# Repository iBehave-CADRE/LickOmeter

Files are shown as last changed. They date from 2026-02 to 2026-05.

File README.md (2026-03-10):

# LickOmeter

This is a guide to build your own motorized LickOmeter based on the arduino capacitive sensor library. Measuring the capacity allows detection of individual licks and therefore direct reward acceptance in the context of many different behavioral research experiments. The final product, can run individually as an embedded system and allows integration with other devices for behavioral research. The repository provides all necessary information to reproduce this device and coding exercises for the general understanding of the resulting data.

Only basic Arduino skills like connecting and uploading code are required for this tutorial.

---

## System Integration

The device modular integration in existing experimental instruments using 5V Digital/Analog TTL signaling via coaxial BNC cables (e.g. with NI-DAQ, cDAQ or dSpace Microlabox) or using Serial Communication via a USB cable (e.g. Python, MATLAB, Bonsai). For the future, integration in the bPod system is planned.

The current firmware allows to control the position of the lickspout with a 5V Digital via a coaxial BNC cable (0V):

0V (LOW) -> Lickspout OUT  
5V (HIGH) -> Lickspout IN

Coupling the Lick-OUT signal with a syringe pump, peristaltic pump or solenoid valve allows controlled application of reward. Also, the LickOmetor can run independently if powered with a 12V power supply and does not necessarily need to be connected to a computer.

Modification of this firmware would also allow to control the lickspout with Serial Communication via USB.

---

## Lickspout Motorization

Currently, two actuators are implemented for custom use cases. The rotary actuator directly couples servo motor rotation to the lickspout, while the linear actuator transforms servo motor rotation via a gear-rack system to linear motion.

### Rotary Actuator

<p align="center">
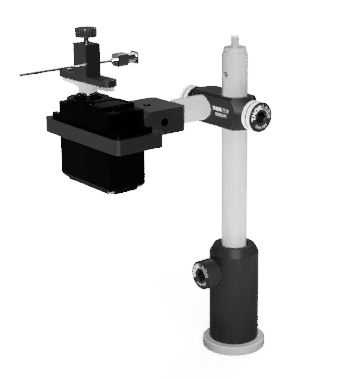
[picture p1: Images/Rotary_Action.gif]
  
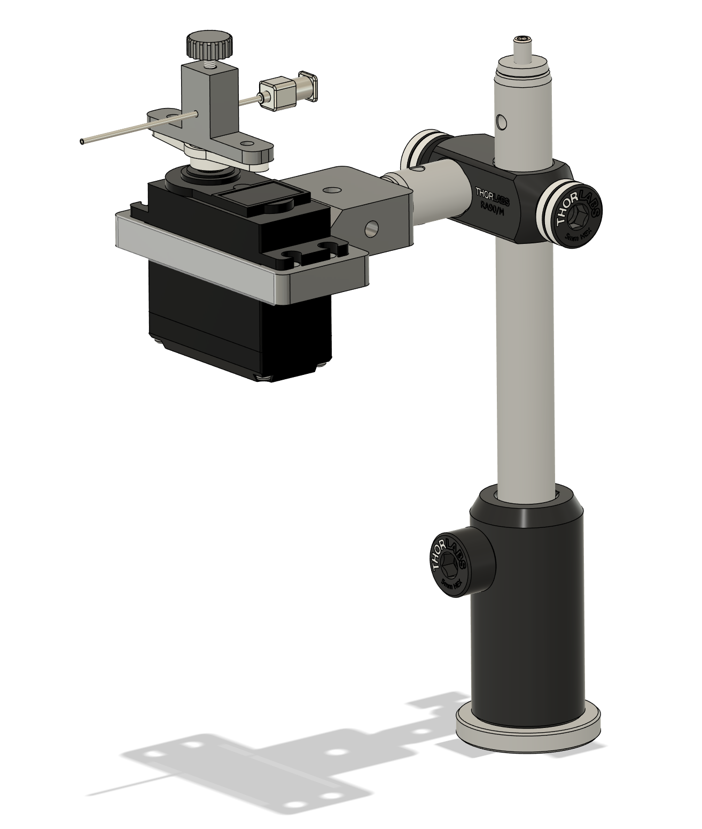
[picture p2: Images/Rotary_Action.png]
  
</p>

**Figure 1:** Rotary actuator can show or hide the lickspot to a specimen in a headfixed experimental setup with for example imaging of neuronal activity in behavioral research.

### Linear Actuator

<p align="center">
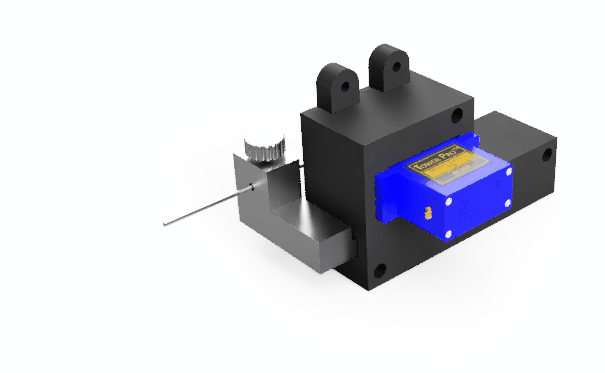
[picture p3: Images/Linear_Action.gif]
  
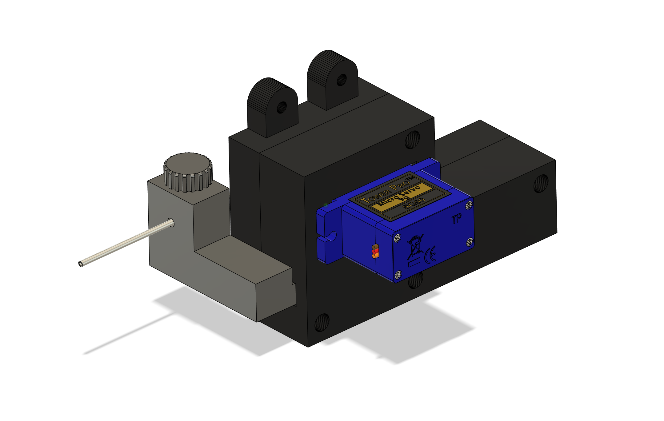
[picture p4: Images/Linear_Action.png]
  
</p>

**Figure 2:** Linear actuator adapted from [OHRBETS Repository](https://github.com/agordonfennell/OHRBETS) with modified Lickspout holder for [Hugo Basile Delta Maze](https://ugobasile.com/products/categories/mazes-tracking/delta-maze). Modified holder is available [here](/Manufacturing_Files/Linear_Action/).

---

## Electronics

In the [Arduino Capacitive Sensor Library](https://playground.arduino.cc/Main/CapacitiveSensor/), the working principle is explained as follows:

>"The capacitiveSensor method toggles a microcontroller send pin to a new state and then waits for the receive pin to change to the same state as the send pin. A variable is incremented inside a while loop to time the receive pin's state change. The method then reports the variable's value, which is in arbitrary units."

>"The physical setup includes a medium to high value (100 kilohm - 50 megohm) resistor between the send pin and the receive (sensor) pin. The receive pin is the sensor terminal. A wire connected to this pin with a piece of foil at the end makes a good sensor. For many applications, a more useful range of values is obtained if the sensor is covered with paper, plastic, or another insulating material, so that users do not actually touch the metal foil. Research has shown that a small capacitor (100 pF) or so from sensor pin to ground improves stability and repeatability."

>"When the send pin changes state, it will eventually change the state of the receive pin. The delay between the send pin changing and the receive pin changing is determined by an RC time constant, defined by R * C, where R is the value of the resistor and C is the capacitance at the receive pin, plus any other capacitance (e.g. human body interaction) present at the sensor (receive) pin. Adding small capacitor (20 - 400 pF) in parallel with the body capacitance, is highly desirable too, as it stabilizes the sensed readings."

For data logging and lick visualization a LED and coaxial BNC connector is connected to a digital port and defined as an output with TTL trigger in the code.

For integrated lickspout motorization, an additional coaxial BNC connector is connected to a digital port with [attachInterrupt() function](https://docs.arduino.cc/language-reference/en/functions/external-interrupts/attachInterrupt/). This allows to detect incoming TTL pulses to remote triggering motor movement. The connected can be any 180° servo motor.

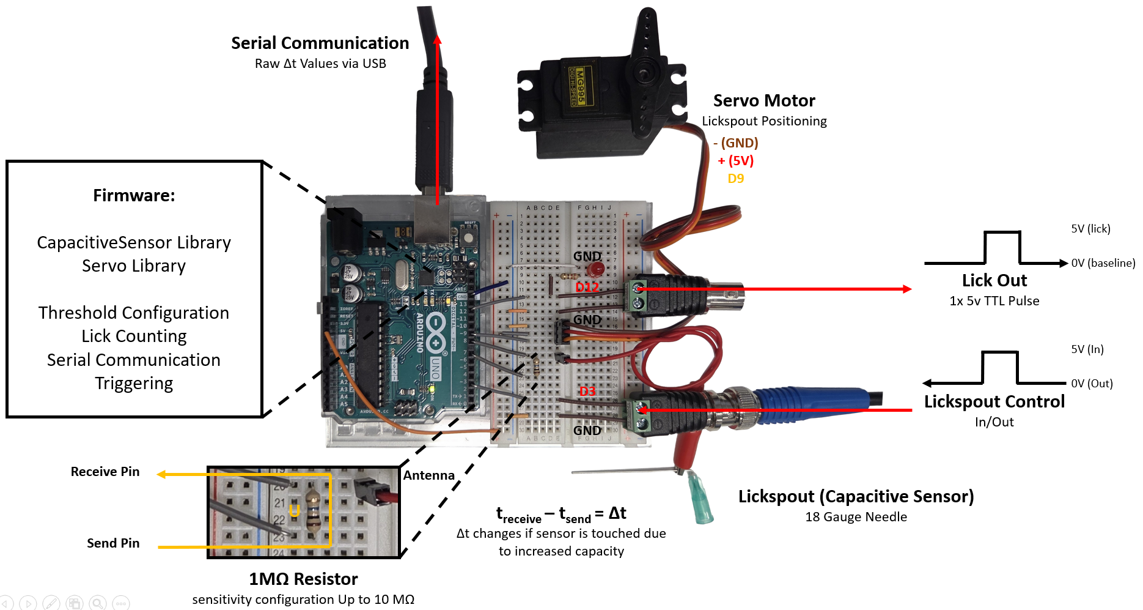
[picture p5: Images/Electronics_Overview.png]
Schematic of LickOmeter


**Figure 3:** Electronics overview of LickOmeter prototype assembly with respective pin assignment.

The CapacitiveSensor Library suggests circuit improvements by adding a capacitor at specific nodes to increase the stability of measured values:

>"Research has shown that a small capacitor (100 pF) or so from sensor pin to ground improves stability and repeatability."

>"Adding small capacitor (20 - 400 pF) in parallel with the body capacitance, is highly desirable too, as it stabilizes the sensed readings."

### Capacitive Sensor Exercises

The following exercises are designed for gaining a profound understanding of how the capacitive sensor actually measures capacitance, how applying and adjusting a threshold allows to filter licking events, how events can be forwarded to synchronization instruments and how motorization can be integrated in one embedded system. For simplicity, a [language reference guide](./Capacitive_Sensor_Exercises/LANGUAGE_REFERENCE.md) with explanation of all used functions is readily provided.

In a first exercise, serial communication between the Arduino and a computer is used to illustrate how the Arduino measures capacitance as an arbitrary value:

- [01_CapacitiveSensor_SerialCom](./01_CapacitiveSensor_SerialCom/README.md)
- [02_CapacitiveSensor_Thresh](./02_CapacitiveSensor_Thresh/README.md)

The next exercise will illustrate, how a 0-5V digital output pin can drive an LED or generate a TTL signal via coaxial BNC cables for communication with a vast number of devices for data acquisition (e.g. NI-DAQ, MicrolaBox etc.). This allows to integrate the device either via serial communication or digital/analog signals to avoid integration hell.

- [03_CapacitiveSensor_ThreshTTL](./03_CapacitiveSensor_ThreshTTL/README.md)

Combining the capacitive sensor and the control of a servo motor can be a difficult task, due to running computational tasks in parallel. Luckily, Arduino provides a solution. The hardware interrupt facilitates parallel computing. The last two exercises will teach how to implement this function for creating a reliable machine with dual function:

- [04_CapacitiveSensor_ThreshTTL_attachInterrupt](./04_CapacitiveSensor_ThreshTTL_attachInterrupt/README.md)
- [05_CapacitiveSensor_ThreshTTL_attachInterrupt_ServoControl](05_CapacitiveSensor_ThreshTTL_attachInterrupt_ServoControl/README.md)

Completion of all five exercises will result in the full replication of the Arduino Firmware. If necessary it can also be downloaded [here](./Firmware/LickOmeter/LickOmeter.ino).

---

## Bill of Materials:

Oscilloscope and or Pulse Generator (BIT-boy) should be available for debugging.

### For Prototyping and Exercises:

|Item|Amount|Link|
|---|---|---|
|Breadboard|1|[Link](https://www.conrad.de/de/p/tru-components-steckplatine-bus-stripe-ausklappbar-polzahl-gesamt-400-l-x-b-82-5-cm-x-54-6-mm-1-st-2885952.html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)|
|Project Holder|1|[Link](https://whadda.com/product/project-holder-for-arduino-uno-development-board-with-breadboard-wpa508/)|
|Jumper Wires Kit|1|[Link](https://www.conrad.de/de/p/tru-components-jumper-kabel-arduino-1x-drahtbruecken-buchse-1x-drahtbruecken-buchse-bunt-2481791.html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)|
|Arduino Uno Rev3|1|[Link](https://store.arduino.cc/products/arduino-uno-rev3)|
|BNC to Screw Clamp|2|[Link](https://www.conrad.de/de/p/tru-components-lt-bnc-f-bnc-steckverbinder-buchse-gerade-50-1-st-1570975.html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)|
|Blunt Stainless Steel Syringe Neegle Gauge 18 (Sigma-Aldrich Z113042-1EA) |1|[Link](https://www.sigmaaldrich.com/DE/de/product/aldrich/z113042)|
|Coaxial BNC Cable 50 Ohm Impedance|2|[Link](https://www.conrad.de/de/p/tru-components-16-0330-bnc-messleitung-1-00-m-schwarz-2108306.html?insert=VQ)|
|Red LED 5mm Diameter|1|[Link](https://www.conrad.de/de/p/tru-components-1573739-led-bedrahtet-rot-rund-5-mm-130-mcd-50-20-ma-2-1-v-1573739.html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)|
|Servo Motor MG995|1|[Link](https://www.conrad.de/de/p/whadda-wpm603-entwicklungsboard-1-st-2481920.html?insert=VQ)|
|Male Pin Header|3|[Link](https://www.conrad.de/de/p/tru-components-tc-9556692-stiftleiste-standard-anzahl-reihen-1-polzahl-je-reihe-40-1-st-2389173.html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)|
|Alligator Clip to Jumper Wire (can also be self made)|1|[Link](https://www.adafruit.com/product/4304)|
|Resistor Kit (1x 10 MOhm for Sensor (can be 100 kOhm to 50 MOhm) 1x 220 Ohm for LED)|1|[Link](https://www.conrad.de/de/p/tru-components-418706-kohleschicht-widerstand-sortiment-axial-bedrahtet-5-390-teile-1564789.html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)|
|USB-A to USB-B Cable 0.5 m|1|[Link](https://www.conrad.de/de/p/renkforce-usb-kabel-usb-2-0-usb-a-stecker-usb-b-stecker-0-50-m-schwarz-vergoldete-steckkontakte-rf-4463067-1487689.html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)|

**Tip:** Many of those parts are also available in the [Arduino Starter Kit](https://store.arduino.cc/products/arduino-starter-kit-multi-language).

### For Enclosure with Power Supply:

The listed parts are required additionally to the above listed items.

|Item|Amount|Link|
|---|---|---|
|Electronics Box|1|[Link](https://www.conrad.de/de/p/donau-elektronik-kgb15-523132-universal-gehaeuse-135-x-95-x-45-polystyrol-eps-grau-1-st-523132.html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)|
|12V Power Supply|1|[Link](https://www.conrad.de/de/p/voltcraft-sng-12-1500-ow-n-steckernetzteil-festspannung-12-v-dc-1-5-a-18-w-offene-kabelenden-2264179.html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)|
|Heat-Shrink Tubing Assortment|1|[Link](https://www.conrad.de/de/p/delock-20735-schrumpfschlauchsortiment-schwarz-1-st-3382844.html?insert=BP)|
|Flexible Jumper Wires|1|[Link](https://www.conrad.de/de/p/renkforce-jkmf403-jumper-kabel-arduino-banana-pi-raspberry-pi-40x-drahtbruecken-stecker-40x-drahtbruecken-buchse-30-2299844.html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)|
|LED Holder|1|[Link](https://www.conrad.de/de/p/tru-components-tc-pcl-5a203-polyamid-6-6-passend-fuer-leds-led-5-mm-snapin-1593487.html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)|
|BNC Connector for Panel Mounting|2|[Link](https://www.conrad.de/de/p/tru-components-tc-9962736-bnc-steckverbinder-buchse-einbau-vertikal-50-1-st-2490684.html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)|
|Fuse Holder for Panel Mounting|1|[Link](https://www.conrad.de/de/p/tru-components-tc-r3-12-sicherungshalter-passend-fuer-sicherungen-feinsicherung-5-x-20-mm-10-a-250-v-ac-1-st-1587496.html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)|
|Fuse 2 Amp|1|[Link](https://www.conrad.de/de/p/eska-522-720-522720-feinsicherung-o-x-l-5-mm-x-20-mm-2-a-250-v-traege-t-inhalt-10-st-523987.html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)|
|On/Off Switch for Panel Mounting|1|[Link](https://www.conrad.de/de/p/tru-components-700185-wippschalter-r13-112a-b-b-0-i-250-v-ac-6-a-1-x-aus-ein-rastend-1-st-1565955.html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)|
|Barrel Plug 12V 2.1 mm for Panel Mount |1|[Link](https://www.conrad.de/de/p/tru-components-niedervolt-steckverbinder-buchse-einbau-vertikal-5-8-mm-2-1-mm-1-st-1567097.html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)|
|Barrel Plug 12V 2.1 mm for Internal Connection|1|[Link](https://www.conrad.de/de/p/tru-components-dc14-m-niedervolt-steckverbinder-stecker-gerade-5-5-mm-2-1-mm-1-st-1570700.html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)|
|USB-B to USB-A Connector for Panel Mounting|1|[Link](https://www.conrad.de/de/p/reversible-usb-durchfuehrung-2-0-buchse-einbau-neu-durchfuehrung-nausb-w-neutrik-inhalt-1-st-746647.html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)|
|USB-B Cable for Internal Connection|1|[Link](https://www.conrad.de/de/p/lindy-usb-kabel-usb-2-0-usb-a-stecker-usb-b-stecker-0-20-m-schwarz-grau-36670-2534819.html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)|
|Red and Black Wire for Power Cabling 0.75 mm2 |1|[Link](https://www.conrad.de/de/p/donau-elektronik-275-01-25-litze-liy-z-2-x-0-75-mm-rot-schwarz-1-st-3594132.html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)|

**Note:** Access to a soldering station, lighter, hand drill and basic tools is required for assembly.

### For Rotary Actuator:

|Item|Amount|Link|
|---|---|---|
|Servo MG995|1|[Link](https://www.conrad.de/de/p/whadda-wpm603-entwicklungsboard-1-st-2481920.html?insert=VQ)|
|Custom 3D-Printed Servo Holder|1|[Link](/Manufacturing_Files/Rotary_Action/Lickspout_Holder.stl)|
|Custom 3D-Printed Lickspout Holder|1|[Link](/Manufacturing_Files/Rotary_Action/Servo_Holder.stl)|
|Custom 3D-Printed Knurled Head Screw|1|[Link](/Manufacturing_Files/Rotary_Action/M3_Knurled_Head_Screw.stl)|
|ThorLabs Pedestal Post Holder 54.7 mm|1|[Link](https://www.thorlabs.com/item/PH50E_M)|
|ThorLabs Right-Angle Clamp for 1/2" Posts|1|[Link](https://www.thorlabs.com/item/RA90_M)|
|ThorLabs Optical Post 40 mm Length|1|[Link](https://www.thorlabs.com/item/TR40_M)|
|ThorLabs Optical Post 150 mm Length|1|[Link](https://www.thorlabs.com/item/TR150_M)|
|Screws, Nuts and Bolts Collection |1||

### For Linear Actuator:

|Item|Amount|Link|
|---|---|---|
|Servo Motor 180° Rotation|1|[Link](https://whadda.com/product/mini-analog-servo-9-g-wpm600/)|
|Custom 3D-Printed Lickspout Holder|1|[Link](/Manufacturing_Files/Linear_Action/Lickspout_Holder.step)|
|Custom 3D-Printed Knurled Head Screw|1|[Link](/Manufacturing_Files/Rotary_Action/M3_Knurled_Head_Screw.stl)|
|Linear Actuator|1|[Link](https://github.com/agordonfennell/OHRBETS)|

**Note:** 3D-printed parts can be printed in PLA with standard print settings on any consumer grade 3D-printer like a [Bambu Lab A1 mini](https://bambulab.com/de-de/a1-mini) for example.

### For Reward Delivery with Syringe Pump:

|Item|Amount|Link|
|---|---|---|
|WPI Syringe Pump AL-1000|1|[Link](https://www.wpi-europe.com/products/pumps--microinjection/laboratory-syringe-pumps/al-1000.aspx)|
|Syringe all glass fortuna optima luer-lock-tip (Sigma-Aldrich, Z31456-1EA, Lot 20228270)|1|[Link](https://www.sigmaaldrich.com/DE/de/search/z314536-1ea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)|
|Serial d-Sub RS-232 extension cable for custom BNC connector and triggering|1|[Link](https://www.conrad.de/de/p/renkforce-seriell-verlaengerungskabel-1x-d-sub-stecker-9pol-1x-d-sub-buchse-9pol-2-00-m-beige-1371918.html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)|
|BNC to Screw Clamp|2|[Link](https://www.conrad.de/de/p/tru-components-lt-bnc-f-bnc-steckverbinder-buchse-gerade-50-1-st-1570975.html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)|
|Luer-to-Tubing Coupler Assortment Kit|1|[Link](https://wpiinc.com/products/504954-luer-to-tubing-coupler-assortment-kit-polypropylene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)|
|PVC Tubing with Luer Ends Masterflex|1|[Link](https://www.fishersci.de/shop/products/fitting-ends-pvc-tubing/11702663#?keyword=tube%20luer)|

#### Custom Made Serial RS-232 to BNC Cable Pin Assignment for Syringe Pump:

|Pin|Definition|Function|Cable|
|---|---|---|---|
|1|VCC (5V)|Logic High Reference, Power Indicator|Red|
|2|Operational Trigger In|Start/Stop Trigger (Configurable, See Manual)|Yellow|
|3|Pumping Direction In|Changes Pumping Direction (Conf., See Manual)|Blue|
|4|Event Trigger In|Event/User Definable Input|White|
|5|Program Out|Program Controlled/User Definable Output|Black|
|6|Program In| Program Conditional/User definable Input|Orange|
|7|Pump Motor Operating Out|High: Pumping; Low Not Pumping (Conf., See Manual)|Purple|
|8|Pumping Direction Out|High: Infuse; Low: Withdraw|Brown|
|9|Ground (0V) Reference|Logic Low Reference|Green|
|Shield|Ground|Cable Ground GND|Copper|

**Note:** The cable coloring is specific to the purchased serial cable and can vary between manufacturers. In some cases a color-pin assignment is provided with the packaging. If not the color-pin assignment can be tested with a multimeter by testing the continuity between each pin and individual cable colors.

**Remote Triggering the Pump:**

- **BNC connector 1:** yellow to Signal (+) and green to GND (-) - for triggering reward application.
- **BNC connector 2:** white to signal (+) and green to GND (-) - for recording pump events with DAQ and subsequent analysis.

**Programming the pump:**

- Press "Diamater/Setup" key and enter the inner syringe diameter im mm for calibration
- Press "Diameter/Setup" key until the first parameter is displayed. Chance the displayed parameter with an any non-arrow key and find "Ln: n". Now press an arrow key under the parameter to set it to"Ln: 1" for low noise mode.
- Press "Diameter/Setup" key until the first parameter is displayed. Chance the displayed parameter with an any non-arrow key and find "ttl". Press an arrow key to show "tr:aa". Press again an arrow key and set the parameter to "tr:T2" (Start Only Reversed). Now, a rising edge from a trigger input signal will start the pumping program.
- Press "Volume" and to change units to μl and enter the desired volume with the arrow keys.

-> The pump will now release the specified amount of μl per trigger pulse.

**Note:** This procedure is specific to this syringe pump model only. If another model is used, check the manual for instructions.

---

## Possible Future Updates

Following ideas are planned to be implemented in the future:

- Compatibility with [Sanworks bPod](https://sanworks.io) system
- Servo control via Serial Communication
- Custom PCB Design

## Links and Resources

- The linear actuator was modified from the [OHRBETS](https://github.com/agordonfennell/OHRBETS) repository.

- The designed was inspired by this a [blog post](https://scanbox.org/2016/04/14/a-simple-lick-o-meter-and-liquid-reward-delivery-system/) of Dario Ringach, PhD at UCLA ([Ringach Lab](http://ringachlab.net)).

- There is official documentation of the [Arduino Capacitive Sensor Library](https://playground.arduino.cc/Main/CapacitiveSensor/) and a [GitHub Repository](https://github.com/PaulStoffregen/CapacitiveSensor) of the maintainer Paul Stoffregen.

- There is official documentation of the [Arduino Servo Library](https://www.arduino.cc/reference/en/libraries/servo/) and an [Arduino Libraries GitHub Repository](https://github.com/arduino-libraries/Servo).

- There is official documentation of the [attachInterrupt() function](https://docs.arduino.cc/language-reference/en/functions/external-interrupts/attachInterrupt/).

---

## References

Development of this project was part of and funded by the [iBehave Network](https://ibehave.nrw). Following laboratories are currently working with the LichOmeter:

- Laboratory of Dr. Sabine Krabbe ([DZNE](https://www.dzne.de/forschung/forschungsbereiche/grundlagenforschung/forschungsgruppen/krabbe/forschungsschwerpunkte/) in Bonn, Germany): Dr. Benjamin Escribano developed the rotary actuator version for a head-fixed intra-vital 2P-Microscopy behavioral experiment.

- Laboratory of Prof. Jan Gründemann ([DZNE](https://www.dzne.de/forschung/forschungsbereiche/grundlagenforschung/forschungsgruppen/gruendemann/forschungsschwerpunkte) in Bonn, Germany): Eva Sebastian developed the linear actuator version for the [Hugo Basile Delta Maze](https://ugobasile.com/products/categories/mazes-tracking/delta-maze).

- Laboratory of Prof. Heinz Beck ([IEECR](https://ieecr-bonn.de), in Bonn, Germany): Bela Erlinghagen further developed the [Multiport Arena](https://github.com/BelaErlinghagen/MultiportArena) with the [Multiport Lickport](https://github.com/BelaErlinghagen/Multiport_Lickport). Josephine Timm further developed a version with randomized food application after a defined running period in the head-fixed [Treadwall](https://github.com/0815Phine/Treadwall) system with intra-vital 2P-Microscopy.

## Contact

This GitHub Repository is created ad maintained by Dr. Benjamin Escribano @ The CADRE - Collaborative Accelerator for Development and Research Engineering ([contact](https://ibehave.nrw/ibots-platform/CADRE/)).

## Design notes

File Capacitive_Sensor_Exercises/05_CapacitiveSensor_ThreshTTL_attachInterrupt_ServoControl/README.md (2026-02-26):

# Exercise 05: Capacitive Sensor with Treshold, TTL Out and Attach Interrupt Servo Control

<p align="center">
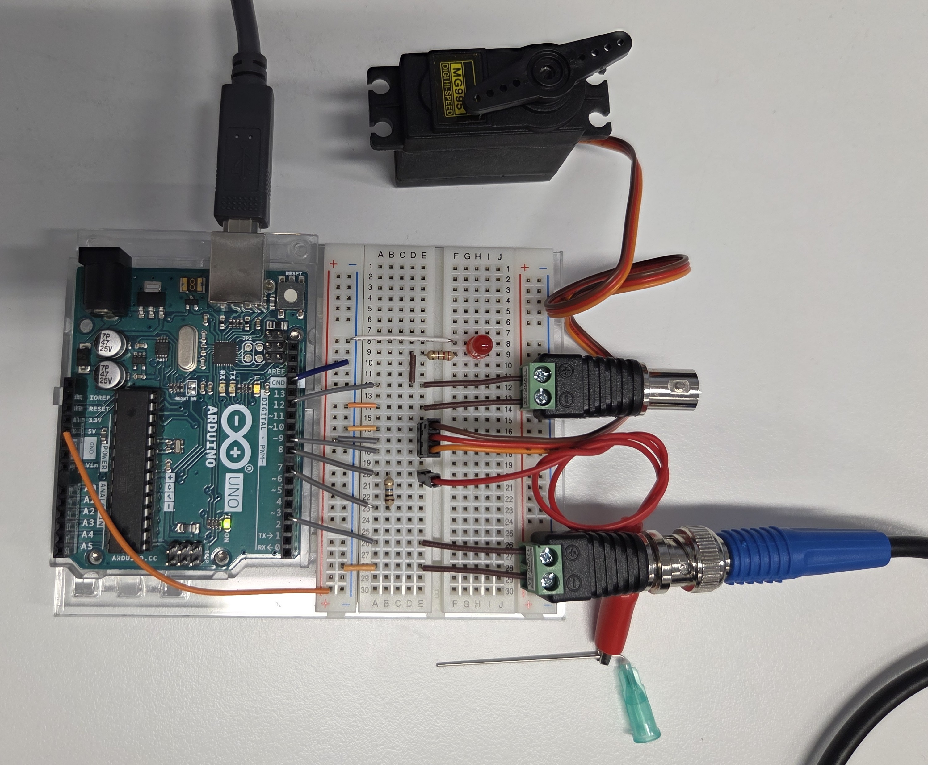
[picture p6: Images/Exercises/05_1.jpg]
  
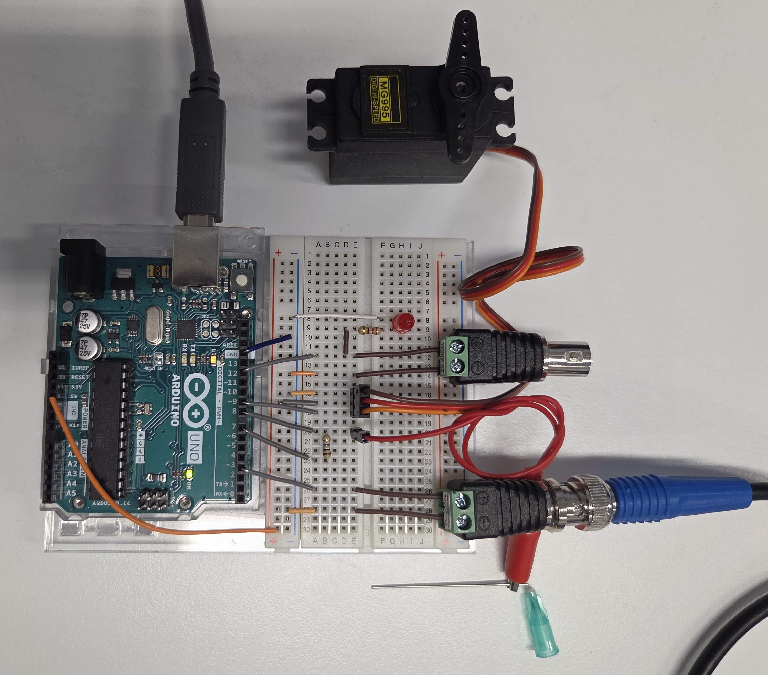
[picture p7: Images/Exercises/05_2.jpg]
  
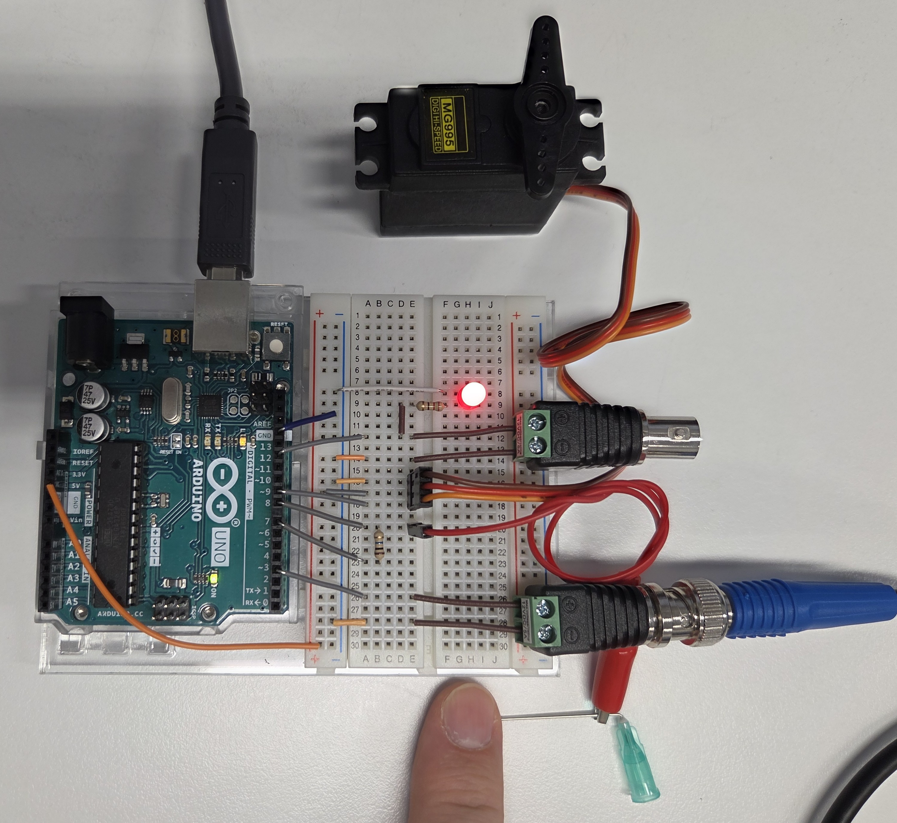
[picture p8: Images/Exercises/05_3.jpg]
  
</p>

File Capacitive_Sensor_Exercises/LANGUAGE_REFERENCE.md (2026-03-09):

# Arduino Language Reference - LickOmeter Project

### `#include <Arduino.h>`
**Purpose:** Includes the Arduino functions for controlling the device. Must be included at the beginning of the script to use related functions.

**Usage:**
```cpp
#include <Arduino.h>
```
---

### `void setup()`
**Purpose:** Runs once when the Arduino powers on or resets. Used to initialize pins, start serial communication, and configure the system.

**Usage:**
```cpp
void setup() {
    // Initialization code here
}
```
---

### `void loop()`
**Purpose:** Runs repeatedly after setup() completes, forming the main program loop. This is where your program's continuous logic lives.

**Usage:**
```cpp
void loop() {
    // Code runs repeatedly
}
```
---

### Constructor: `CapacitiveSensor(sendPin, receivePin)`
**Purpose:** Creates a CapacitiveSensor object that will measure capacitance between two pins.

**Usage:**
```cpp
CapacitiveSensor cs_7_8 = CapacitiveSensor(7, 8);
```

**Parameters:**
- `sendPin` (int): The pin that sends the signal (also called the "send" or "drive" pin)
- `receivePin` (int): The pin that receives the signal (also called the "sense" or "receive" pin)

**Return Value:** A new CapacitiveSensor object

**Hardware Requirements:** A 10MΩ resistor must be connected between sendPin and receivePin. An optional antenna can be connected to receivePin for increased sensitivity.

**Example Variables:**
- `CapacitiveSensor cs_7_8 = CapacitiveSensor(7, 8);` - Sensor on pins 7 and 8
- `CapacitiveSensor cs_4_2 = CapacitiveSensor(4, 2);` - Sensor on pins 4 and 2

---

### `capacitiveSensor(samples)`
**Purpose:** Reads and returns the capacitive sensor value. The sensor measures the time it takes for the capacitance to charge/discharge.

**Usage:**
```cpp
long sensorValue = cs_7_8.capacitiveSensor(80);
```

**Parameters:**
- `samples` (int): Number of samples to average. Higher values = more accurate but slower response
  - Typical range: 30-100
  - Lower samples (30): Faster response, more noise
  - Higher samples (100+): Slower response, more stable readings

**Return Value:** long integer representing capacitance in arbitrary units (typically 0-1000+ depending on sensor design)

**Important Notes:**
- This function should be called in the loop()
- Blocking function: pauses execution while reading
- Raw values without filtering can be noisy

**Example Variables:**
```cpp
long rawSensorValue = cs_7_8.capacitiveSensor(80);
long smoothSensorValue = cs_7_8.capacitiveSensor(30);  // Faster but noisier
```

---

## Serial Communication Functions

### `Serial.begin(baudRate)`
**Purpose:** Initializes serial communication between the Arduino and a computer at a specified data rate.

**Usage:**
```cpp
Serial.begin(9600);
```

**Parameters:**
- `baudRate` (long): The speed of serial communication in bits per second (baud)
  - Common values: 9600, 115200
  - 9600: Standard, reliable, slower
  - 115200: Faster, requires proper hardware support

**Return Value:** void (nothing)

**Location:** Call this in `setup()`, typically as the first command

**Note:** The Serial Monitor in Arduino IDE must be set to the same baud rate to display data correctly.

---

### `Serial.println(value)`
**Purpose:** Prints a value to the serial monitor and adds a newline character at the end.

**Usage:**
```cpp
Serial.println(42);           // Prints "42" with newline
Serial.println("Hello");      // Prints "Hello" with newline
Serial.println(2.5);          // Prints "2.50" with newline
```

**Parameters:**
- `value` (various types): The data to send
  - int: `Serial.println(100)`
  - float/double: `Serial.println(3.14)`
  - String: `Serial.println("Text")`
  - char: `Serial.println('A')`

**Return Value:** Number of bytes written (int)

**Related Functions:**
- `Serial.print(value)` - Same as println() but without newline
- `Serial.write(value)` - Sends raw byte value

**Example Variables:**
```cpp
long sensorValue = 250;
if (sensorValue > 10) {
    Serial.println(sensorValue);  // Outputs "250" to serial monitor
}
```
---

## Control Flow & Timing

### `delay(milliseconds)`
**Purpose:** Pauses program execution for a specified number of milliseconds.

**Usage:**
```cpp
delay(1000);  // Pause for 1 second
delay(10);    // Pause for 10 milliseconds
```

**Parameters:**
- `milliseconds` (unsigned long): How long to pause
  - 1000 milliseconds = 1 second
  - 1 millisecond = 0.001 seconds

**Return Value:** void (nothing)

**Side Effects:** All other operations pause entirely (blocking)

**Common Use Cases:**
- Reducing serial monitor output
- Creating temporal separation between sensor reads
- Debouncing switches
- Creating timing intervals

**Example Variables:**
```cpp
delay(10);      // 10 millisecond delay
delay(500);     // 500 millisecond (0.5 second) delay
delay(1000);    // 1 second delay
```

---

### `if (condition) { ... }`
**Purpose:** Executes code only if a condition is true.

**Usage:**
```cpp
if (cs > 10) {
    Serial.println(cs);
}
```

**Parameters/Conditions:**
- `>` : greater than
- `<` : less than
- `==` : equal to
- `!=` : not equal to
- `>=` : greater than or equal
- `<=` : less than or equal
- `&&` : AND operator (both conditions true)
- `||` : OR operator (either condition true)

**Example Variables:**
```cpp
if (sensorValue > 10) { ... }           // Executes if sensorValue exceeds 10
if (sensorValue < 0) { ... }            // Executes if sensorValue is negative
if (sensorValue == 0) { ... }           // Executes if sensorValue equals 0
if (sensorValue > 10 && value < 100) { ... }  // Both conditions must be true
```

---

## Data Types

### `long`
**Purpose:** Stores large integer values (used for sensor readings that can be large).

**Range:** -2,147,483,648 to 2,147,483,647

**Usage:**
```cpp
long sensorReading = 1500;
```

### `void`
**Purpose:** Indicates a function returns no value or has no parameters.

**Usage:**
```cpp
void setup() { }  // Returns nothing
```

### `int`
**Purpose:** Stores smaller integer values.

**Range:** -32,768 to 32,767

**Usage:**
```cpp
int sensorSamples = 80;
```

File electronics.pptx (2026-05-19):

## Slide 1

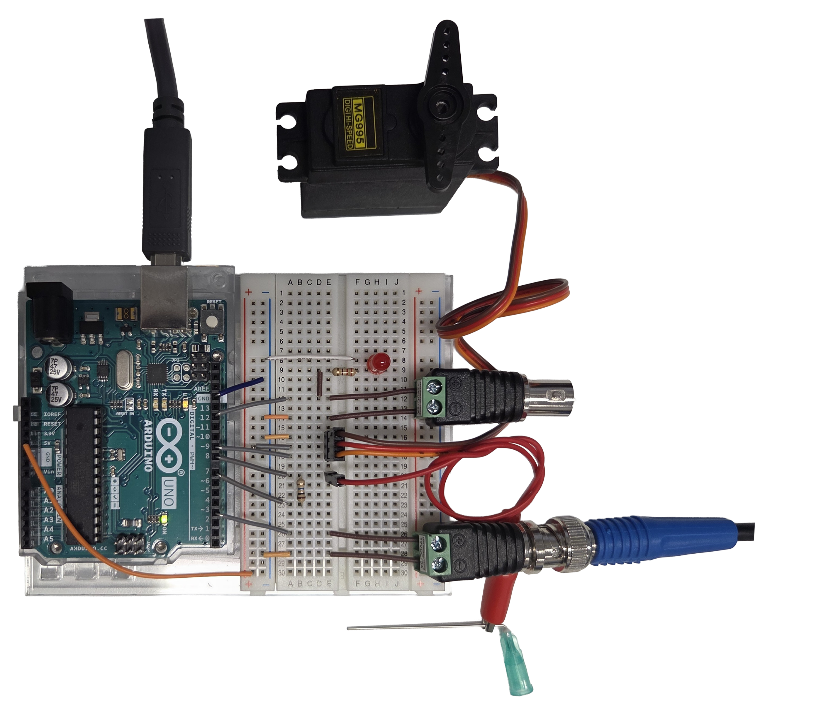
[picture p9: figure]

Serial Communication
Raw Δt Values via USB

Servo Motor
Lickspout Positioning

Firmware:

CapacitiveSensor Library
Servo Library

Threshold Configuration
Lick Counting
Serial Communication
Triggering

- (GND)
+ (5V)
D9

5V (lick)

GND

D12

Lick Out
1x 5v TTL Pulse

0V (baseline)

GND

5V (In)

D3

Lickspout Control
In/Out

0V (Out)

GND

Receive Pin

1MΩ Resistor
sensitivity configuration Up to 10 MΩ

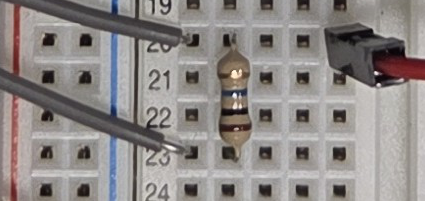
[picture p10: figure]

U

Antenna

treceive – tsend = Δt
Δt changes if sensor is touched due to increased capacity

Lickspout (Capacitive Sensor)
18 Gauge Needle

Send Pin

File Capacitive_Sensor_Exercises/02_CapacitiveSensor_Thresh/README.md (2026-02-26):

# Exercise 02: 

<p align="center">
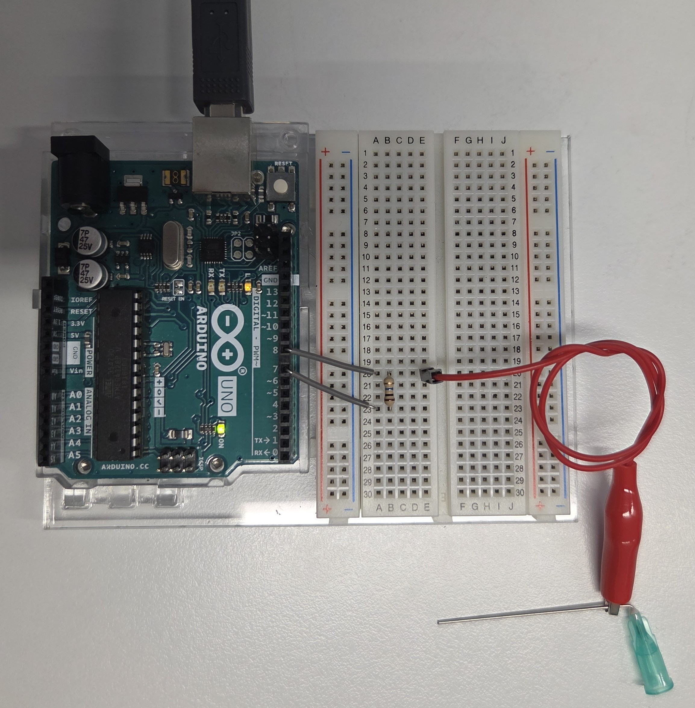
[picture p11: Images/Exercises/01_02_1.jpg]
  
</p>

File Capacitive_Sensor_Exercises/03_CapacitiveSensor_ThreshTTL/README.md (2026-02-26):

# Exercise 03: 

<p align="center">
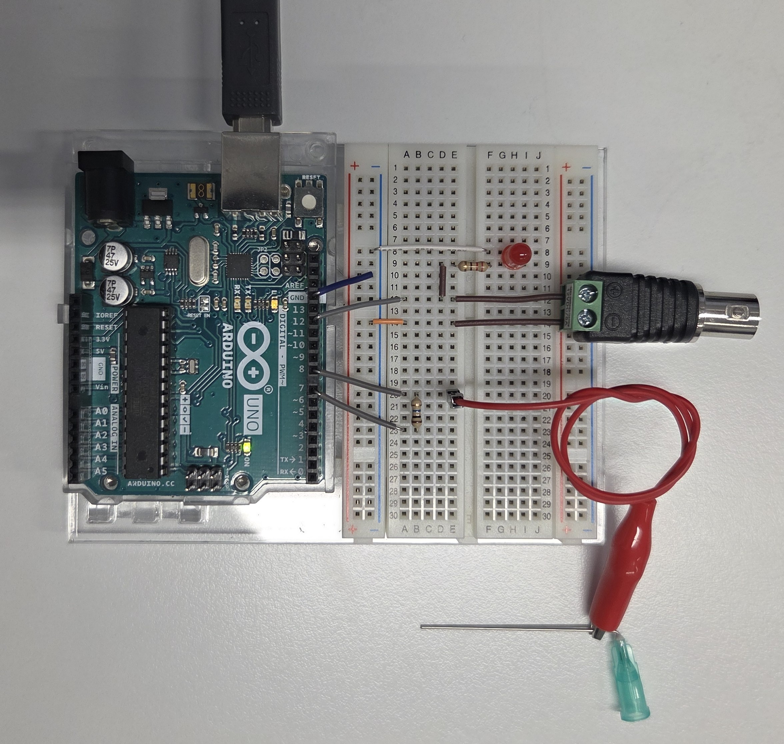
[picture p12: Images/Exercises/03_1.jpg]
  
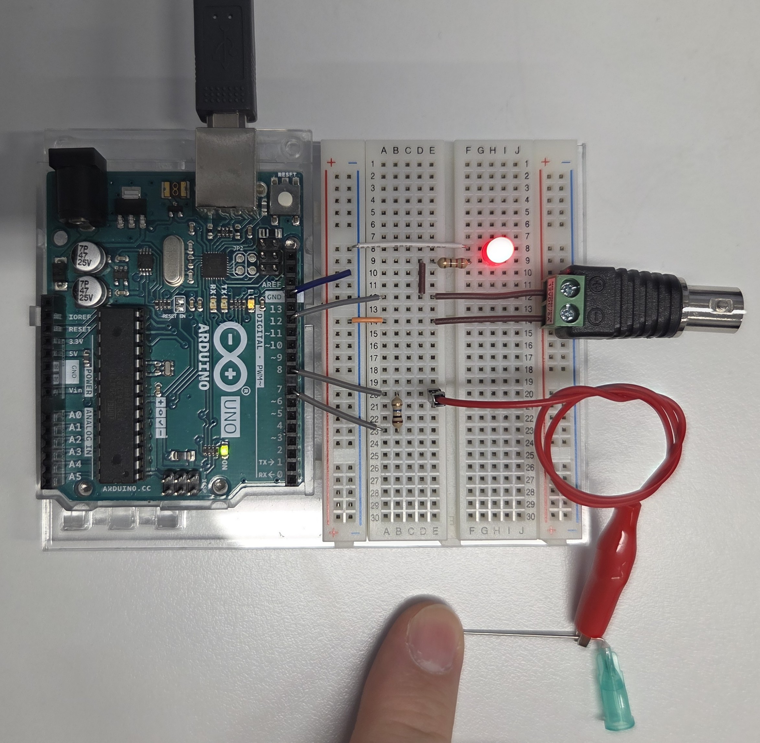
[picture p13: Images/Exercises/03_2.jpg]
  
</p>

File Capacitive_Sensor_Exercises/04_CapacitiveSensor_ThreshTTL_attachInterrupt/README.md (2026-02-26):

# Exercise 04: 

<p align="center">
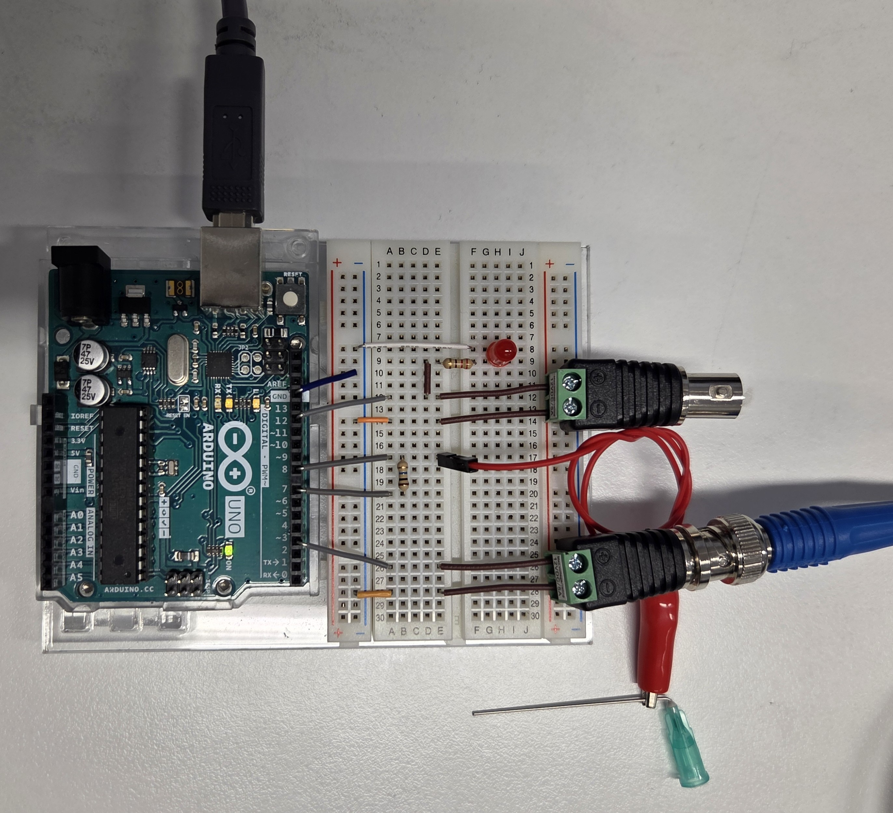
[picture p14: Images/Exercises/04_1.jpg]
  
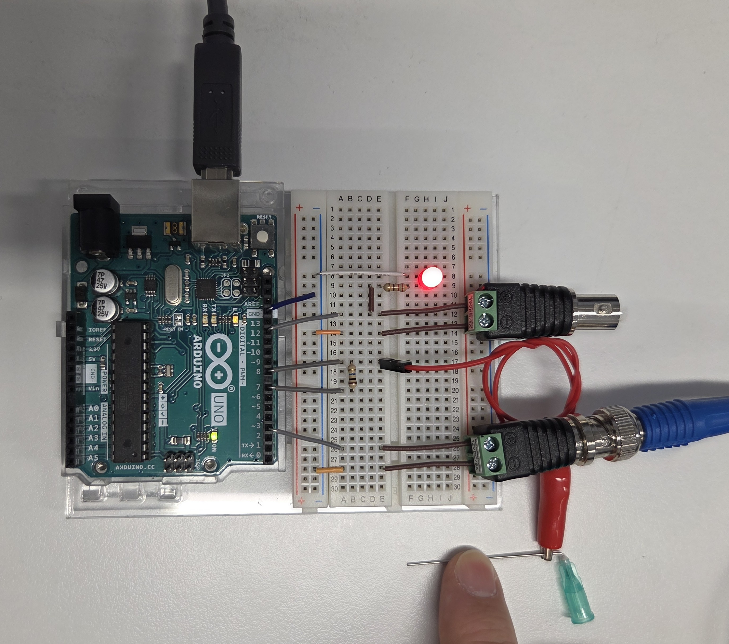
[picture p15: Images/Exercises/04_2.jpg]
  
</p>

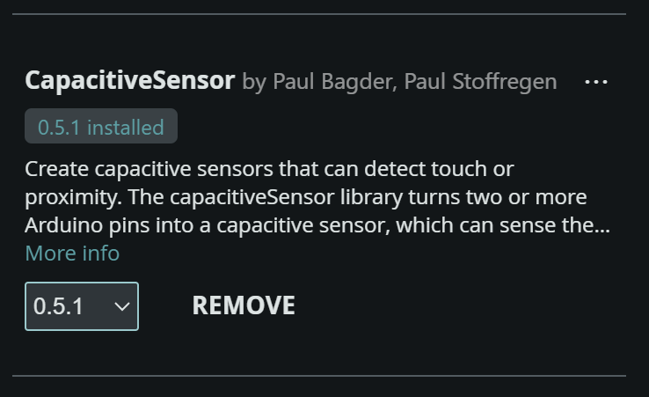
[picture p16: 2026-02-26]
Images/CapacitiveSensor_Library.png

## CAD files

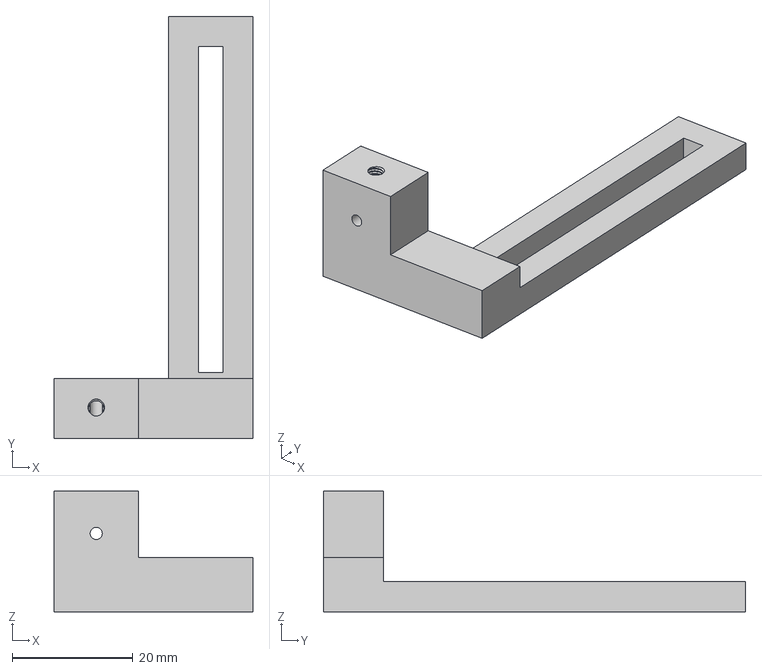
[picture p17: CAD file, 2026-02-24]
Manufacturing_Files/Linear_Action/Lickspout_Holder.step
33.0 x 70.0 x 20.0 mm

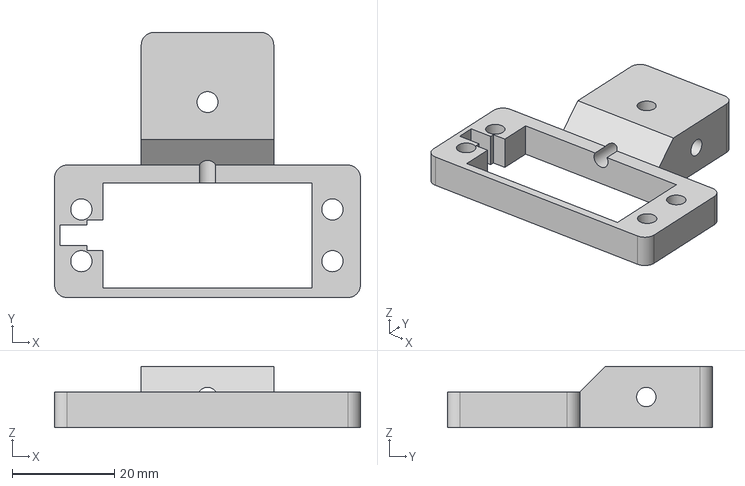
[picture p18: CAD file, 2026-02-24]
Manufacturing_Files/Rotary_Action/Servo_Holder.step
60.0 x 52.0 x 12.0 mm

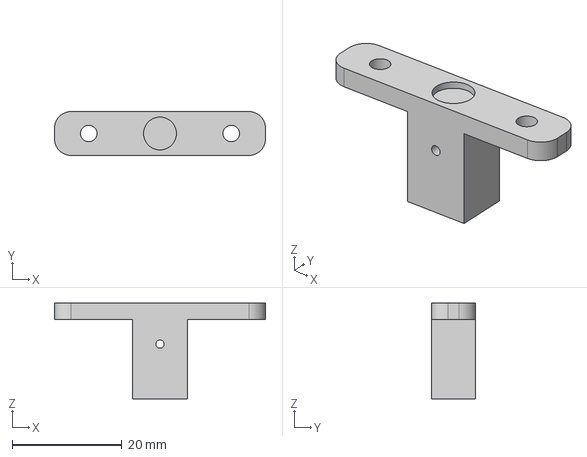
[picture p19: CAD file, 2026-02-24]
Manufacturing_Files/Rotary_Action/Lickspout_Holder.step
38.5 x 8.00 x 17.5 mm

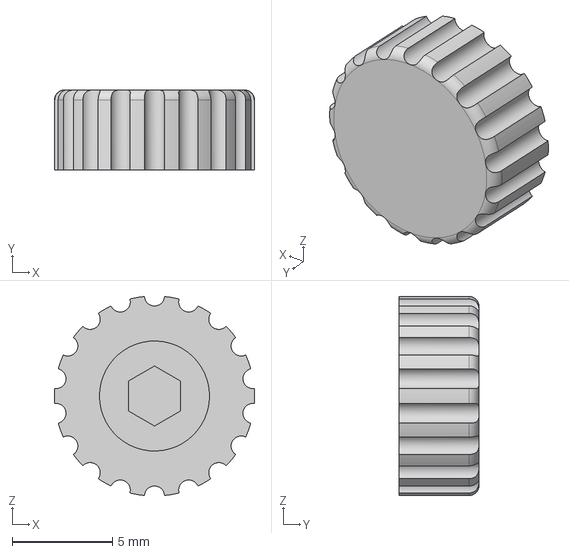
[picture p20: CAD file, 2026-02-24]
Manufacturing_Files/Linear_Action/M3_Knurled_Head_Screw.step
10.00 x 4.00 x 9.95 mm

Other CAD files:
Manufacturing_Files/Linear_Action/Lickspout_Holder.stl
Manufacturing_Files/Linear_Action/M3_Knurled_Head_Screw.stl
Manufacturing_Files/Rotary_Action/Lickspout_Holder.stl
Manufacturing_Files/Rotary_Action/Servo_Holder.stl

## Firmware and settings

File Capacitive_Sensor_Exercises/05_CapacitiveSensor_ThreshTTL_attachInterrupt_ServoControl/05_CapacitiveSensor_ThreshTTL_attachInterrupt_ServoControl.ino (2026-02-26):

#include <Servo.h>
#include <CapacitiveSensor.h>


Servo myservo;  // create servo object to control a servo
CapacitiveSensor cs_7_8 = CapacitiveSensor(7,8); //10M Resistor between pins 7 and 8, you may also connect an antenna on pin 8. If the antenna is connected to pin 7 it will sense touch-release...
unsigned long csSum; // This variable stores accumulates capacitive values till reaching a threshold

//Variables for encoding servo positions
int ServoMotorOutPosition = 0; //Variable to store a value for the servo motor position where it is out of reach
int ServoMotorInPosition = 120; //Variable to store a value for the servo motor position where it is in reach
int CurrentServoMotorPosition = 0; //Variable to store the current position of the servo motor
int i = 0;

//Variables to for storing input value changes and input states of the input pin to control servo motor
int InputState = 0;
volatile bool InputChange = false; //Volatile bool for variables in attached interrupt


void setup() {
    Serial.begin(9600); // Begin serial communication
    pinMode(12, OUTPUT); //LED (to signal touches) is on pin 12 
    myservo.attach(9);
    pinMode(3, INPUT_PULLUP);
    attachInterrupt(digitalPinToInterrupt(3), DetectInputChange, CHANGE);
    delay(50);
    myservo.write(ServoMotorOutPosition);
    CurrentServoMotorPosition = myservo.read();
    Serial.println(CurrentServoMotorPosition);
}

void loop() {
  noInterrupts();
  CapacitiveSensorRead(); // This time we put everything in a function
  ServoMotorInOut();
  interrupts();
}

void CapacitiveSensorRead() {
    long cs = cs_7_8.capacitiveSensor(80); // Sensor resolution is set to 80; will store the capacitance as an arbitrary value
	if (cs > 100) { //Arbitrary number; lower threshold
		csSum += cs; // Same as csSum = csSum + cs ; cumulative value for reachiung threshold
		Serial.println(cs); 
		if (csSum >= 3800) //Testing if csSum reached threshold, a High value means it takes longer to trigger
		{
			Serial.print("Trigger: ");
			Serial.println(csSum);
      BlinkLEDandTTLout();
			if (csSum > 0) { csSum = 0; } //Reset of csSum
			cs_7_8.reset_CS_AutoCal(); //Stops readings and recalibration of capacitive sensor
		}
	} else {
		csSum = 0; //Timeout caused by bad readings
	}
}

void BlinkLEDandTTLout() {
      digitalWrite(12, HIGH);  //  if a lick is detected, turn LED ON.
      delay(1);
      digitalWrite(12, LOW);  //  turn the LED OFF.
  }

void DetectInputChange() {
    InputChange = true;
    Serial.println("Change Detected");
}

void ServoMotorInOut() {
  if (InputChange==true) { // If there was a change of state on the input pin
    InputState = digitalRead(3); // Detect to which state it hast changed...high or low...high means in low means out
    if (InputState == HIGH) { // If the state is high rotate the servo to the in position
      for (i = CurrentServoMotorPosition; i <= ServoMotorInPosition; i += 1) {
        myservo.write(i); delay(15);
        }
        CurrentServoMotorPosition = myservo.read(); //save the current position of the servo
    } else { // otherwise rotate it to the out position
      for (i = CurrentServoMotorPosition; i >= ServoMotorOutPosition; i -= 1) {
        myservo.write(i); delay(15);
        }
        CurrentServoMotorPosition = myservo.read(); //save the current position of the servo
    }
    InputChange == false; //Reset Change Detection to no change detected
  }
}

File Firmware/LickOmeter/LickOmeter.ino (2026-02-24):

#include <Servo.h>
#include <CapacitiveSensor.h>

Servo myservo;  // create servo object to control a servo

CapacitiveSensor cs_10_11 = CapacitiveSensor(10, 11);  //10M Resistor between pins 2 and 3, you may also connect an antenna on pin 8
unsigned long csSum;

//Variables for Code
int RewardThresh = 1; // 
int LickCounter = 0; //
int ServPosOut = 4; // starting position of servo (from where its strating to drive out)
int ServPosIn = 68; // Servo Position when out, how far to drive out
int ServSignalIn = 0;
int ServStatus = 0;
int ServoPos = 0;   // <------ variable to store the rotation in degrees of the servo motor.
volatile bool ChangeDetected = false;

void setup() {
  // Servo Control is attached to pin 8
  myservo.attach(8);
  myservo.write(ServPosOut);
  delay(50);
  //LED is on pin 12 // with 220 Ohm resistor at longer side/ Pin 12 (red) side
  pinMode(12, OUTPUT);
  //Lick OUT is on pin 9
  pinMode(9, OUTPUT);
  //Servo IN os on pin 3
  //digitalWrite(10, LOW);
  pinMode(3, INPUT_PULLUP);
  attachInterrupt(digitalPinToInterrupt(3), ServoInDetectChange, CHANGE); // important function, needs to be special pin (e.g., 3) where its possible to excecute functions and interrupt. If lick detected then stop and move to last code and say true than new loop started
  myservo.write(ServPosOut);
  ServStatus = myservo.read();
}

void loop() { 
  noInterrupts();
  LickDetect();
  ServControl();
  interrupts();
}

void LickDetect() {
  long cs = cs_10_11.capacitiveSensor(80);  //a: Sensor resolution is set to 80
  if (cs > 100) {                         //b: Arbitrary number
    csSum += cs;
    if (csSum >= 2300)  //c: This value is the threshold, a High value means it takes longer to trigger #original value = 3800
    {
      LickCounter = LickCounter + 1;
      LickOut();      
      if (csSum > 0) { csSum = 0; }  //Reset
      cs_10_11.reset_CS_AutoCal();     //Stops readings
    }
  } else {
    csSum = 0;  //Timeout caused by bad readings
  }
}

void LickOut() {
  if (LickCounter == RewardThresh) {
    digitalWrite(12, HIGH);  //  if a lick is detected, turn LED ON.
    digitalWrite(9, HIGH);   // TTL out start
    delay(1);
    digitalWrite(9, LOW);   // TTL out stop
    digitalWrite(12, LOW);  //  turn the LED OFF.
    LickCounter = 0;
  }
}
  
void ServControl() {
  if (ChangeDetected==true) {
    ServSignalIn = digitalRead(3);
    if (ServSignalIn == HIGH) {
      for (ServoPos = ServStatus; ServoPos <= ServPosIn; ServoPos += 1) {myservo.write(ServoPos); delay(10);}
      ServStatus = myservo.read();
    } else {
      for (ServoPos = ServStatus; ServoPos >= ServPosOut; ServoPos -= 1) {myservo.write(ServoPos); delay(10);}
      ServStatus = myservo.read();
    }
    ChangeDetected == false; //Reset Change Detection
  }
}

void ServoInDetectChange() {
  ChangeDetected = true; // if true than lick-spout drives out
}

// Stecker für Lick-spout:
// 1. Lick-spout, 2. PIN (orangenes Kabel Servo ), 3. Strom (rotes Kabel Servo), 4. GND (braunes Kabel Servo)

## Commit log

2026-02-24 colecting materials
2026-02-24 collected files rotary action
    [Lickspout_Holder.step, Lickspout_Holder.stl, M3_Knurled_Head_Screw.step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]
2026-02-24 more renderings and manuf files
    [Lickspout_Holder.step, Lickspout_Holder.stl, M3_Knurled_Head_Screw.step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]
2026-02-26 more material
